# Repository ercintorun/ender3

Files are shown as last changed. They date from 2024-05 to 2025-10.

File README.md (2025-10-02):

# 🛠️ Heavily Modified Ender 3 Pro Setup

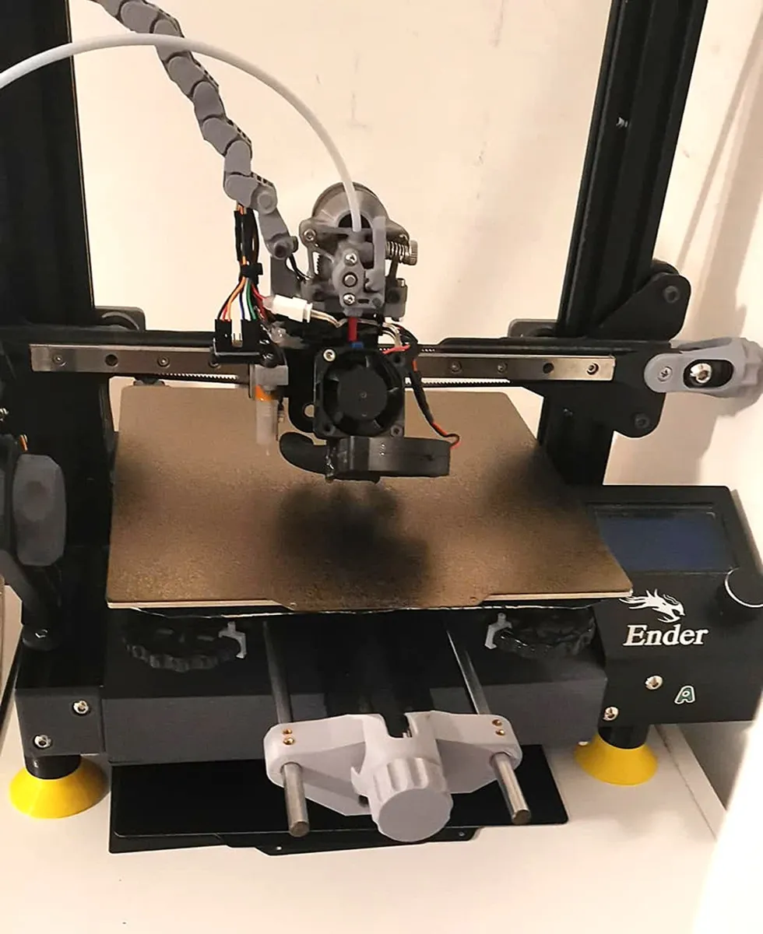
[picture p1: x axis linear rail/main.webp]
Ender 3 Pro with X-axis linear rail


---

## 🔧 Hardware Modifications

My Ender 3 Pro includes the following upgrades:

- 🧠 **Mainboard**: BTT SKR Mini E3 V2 (buy v3 to use spi for adxl345) 
- 🍓 **Controller**: Raspberry Pi  3b
- ➖ **X Axis**: Linear Rail  
- ➖ **Y Axis**: Linear Rods  
- 📐 **Sensor**: ADXL345  
- 📍 **Auto Bed Leveling**: 3DTouch  
- 🔥 **Hotend**: Bambu-style  
- 🌬️ **Part Cooling Fan**: 5015  
- 🌡️ **Hotend Cooling Fan**: 4020  

---

## 📂 Repository Contents

- 🧾 **[Klipper Installation - Configuration](klipper.md)**
- 🖨️ **[Printed Upgrade Links**](printupgrades.md)**  
- 🧪 **[Calibration-Tuning](calibration.md)**
- ⚙️ **Cura & PrusaSlicer Start/End G-code Templates**
- 🔧 **[ADXL345 on Skr Mini E3 v2.0](adxl345_on_skr_mini_e3_v2.0.md)**
- 🔧 **[Dual ADXL345 on Raspberry Pi](2_adxl345_on_raspberrypi_klipper.md)**
- 🔧 **[Chamber Temp Sensor DS18B20 on Raspberry Pi](ds18b20_chamber_temp_sensor_raspberrypi_klipper.md)**
- 🔧 **[Ender3 Stock Motor Current Configs for Klipper on SKR Mini E3 v2.0](motor_currents.md)**
- 🛒 **[Aliexpress Upgrade Links](buyupgrades.md)**

---
## 🖨️ Example Prints

- 🧵 **PETG Sample**:  
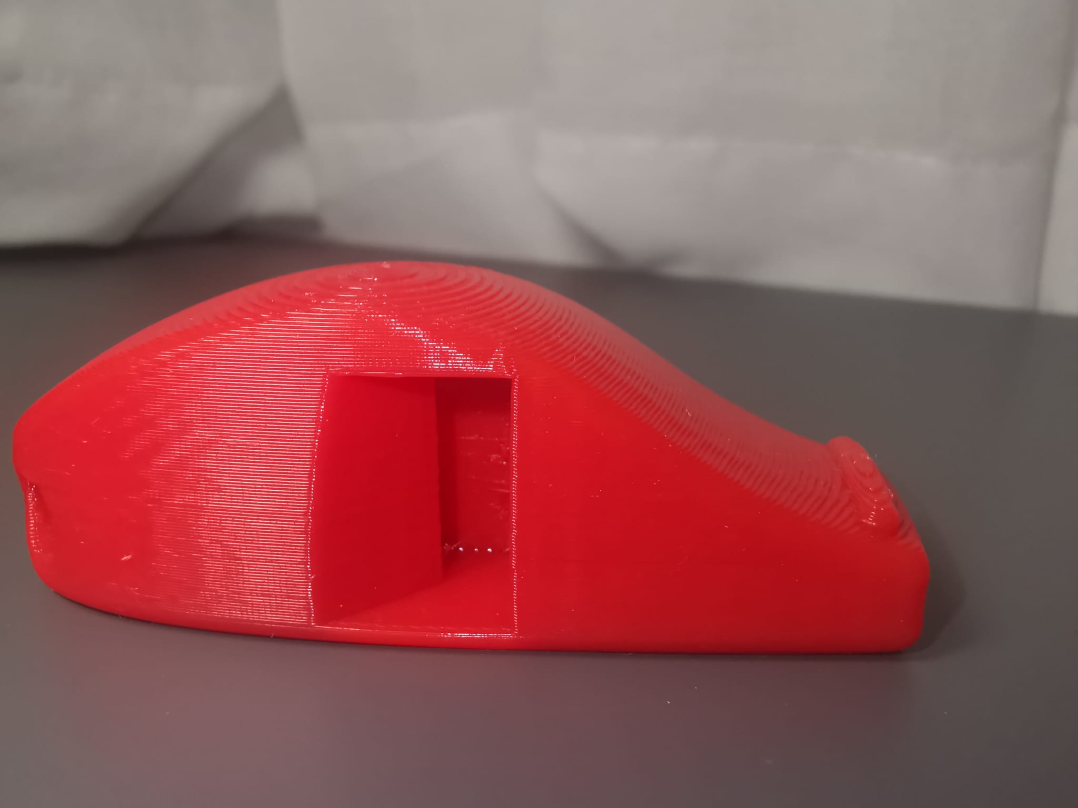
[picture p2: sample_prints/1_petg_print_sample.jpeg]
PETG sample print


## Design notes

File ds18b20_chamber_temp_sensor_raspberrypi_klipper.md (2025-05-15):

Be aware that the Klipper heating code was designed around temperature sensors that provide an update every 300ms. The ds18b20 sensor can only provide updates once every second or so. You may not be able to use a heater with db18b20. If you want to use it than you need to change some part of the heater.py code (you can find the details on https://klipper.discourse.group/t/controlling-a-chamber-heater-through-a-relay-connected-to-rpi4-via-gpio-and-monitored-with-a-ds18b20/11131/18) 

Klipper Configuration

    [mcu host]
    serial: /tmp/klipper_host_mcu
    [temperature_sensor Chamber]
    sensor_type: DS18B20
    serial_no: 10-00080291bf97
    ds18_report_time = 3.0
    sensor_mcu: host

a DS18B20 to GPIO4 (you have to enable 1wire via sudo raspi-config). Use 3.3 and a gnd port also on the raspberry pi. 

    Call sudo raspi-config
    Activate the 1-wire interface
    Reboot
    Call lsmod | grep -i w1_ to verify that the needed Kernel modules are actually loaded 

Source:
https://klipper.discourse.group/t/ds18b20-temperature-sensor-configuration/8429/4
https://klipper.discourse.group/t/controlling-a-chamber-heater-through-a-relay-connected-to-rpi4-via-gpio-and-monitored-with-a-ds18b20/11131/6

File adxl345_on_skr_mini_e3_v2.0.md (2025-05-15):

## 🔧 ADXL345on SKR Mini E3 v2.0

Use the EXP1 connector. You either connect the tft35-screen or the adxl 345 if you use the board.The alternative is to use Raspberry pi SPI pins. The difference between skr mini e3 v3.0 and 2.0  is with the accelerometer's CS pin. The V2.0 board's SPI1 port only has 6 pins, while 3.0 has 8, and it lacks the NSS pin. This board's connector does instead have an "RST" pin, but that's no use. It is not possible to use SPI ports for adxl345 on 2.0 unlike the 3.0. 

    [adxl345]
    cs_pin: PB5
    spi_software_sclk_pin: PB9
    spi_software_mosi_pin: PB8
    spi_software_miso_pin: PB15

    [resonance_tester]
    accel_chip: adxl345
    probe_points:100, 100, 20

If you would like to use the original ender cable to extend the pinouts from EXP1: 
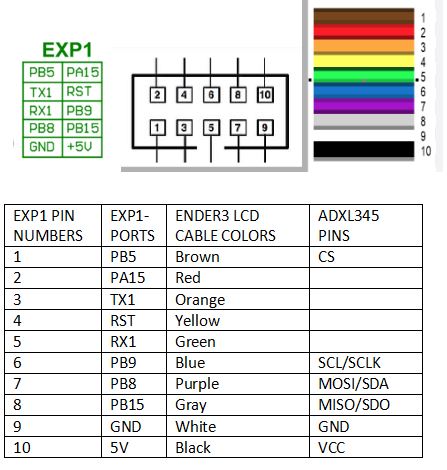
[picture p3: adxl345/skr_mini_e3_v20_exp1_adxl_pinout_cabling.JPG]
PETG sample print


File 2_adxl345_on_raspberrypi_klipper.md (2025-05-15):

## 🔧 ADXL345 Method 2 - 2 ADXL on Raspberry Pi

Follow the instructions on Klipper documentation how to install Raspberry pi as a second MCU and enabling the SPI. 
- https://www.klipper3d.org/RPi_microcontroller.html

You could use spi0 and share the mosi miso and sclk with both chips and use CE0 and CE1 as ADLX345s enable pin. SPI is not designed to use 2 devices at once on the bus but the input calibration doesn't use both at the same time so this is an acceptible setup.

Configuration

    [mcu rpi]
    serial: /tmp/klipper_host_mcu
    [adxl345 hotend]
    cs_pin: rpi:None
    spi_bus: spidev0.0
    [adxl345 bed]
    cs_pin: rpi:None
    spi_bus: spidev0.1
    [resonance_tester]
    accel_chip_x: adxl345 hotend
    accel_chip_y: adxl345 bed
    probe_points: 125, 110, 20

Both ADXL345's will share the same SDA, SDO and SCL, each will have their own CS pin. The config i posted above is accurate for what I'm about to list below for wiring. Remember the RPI MCU does the CS muxing so "cs_pin: rpi:None" is valid for both.

    Both
    SDA = RPI Pin 19 = GPIO10 (SPI0_MOSI)
    SDO = RPI Pin 21 = GPIO09 (SPI0_MISO)
    SCL = RPI Pin 23 = GPIO11 (SPI0_SCLK)
    3V3 (or VCC) = RPI Pin 01 = RPI Pin Name "3.3v DC power"
    GND = RPI Pin 06 = RPI Pin Name "Ground"

    ADXL345 hotend
    CS = RPI Pin 24 = GPIO08 (SPI0_CE0)

    ADXL345 bed
    CS = RPI Pin 26 = GPIO07 (SPI0_CE1)

Pins for spi reference as well as Klipper Doc [SPI Pinout](https://pinout.xyz/pinout/spi) 

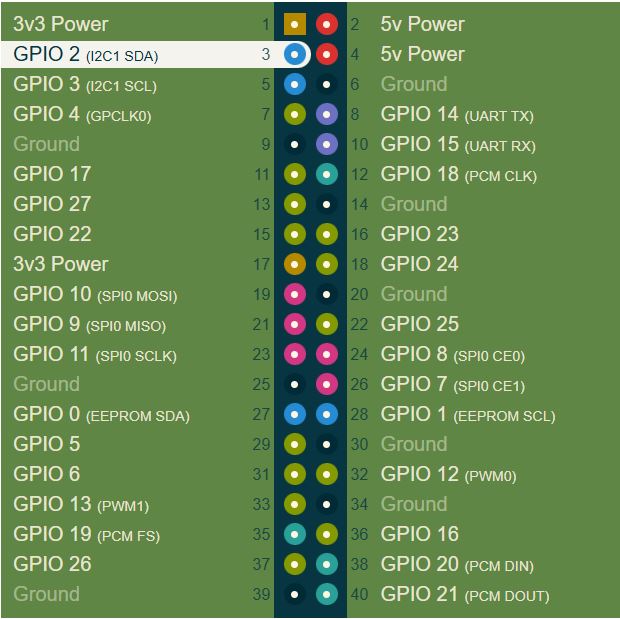
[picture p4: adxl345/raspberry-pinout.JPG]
RaspberryPi Pinout
  

Source for the information: 
- https://www.reddit.com/r/klippers/comments/qkk7un/two_adxl345s_on_one_raspberry_pi/
- https://www.reddit.com/r/klippers/comments/qkk7un/comment/hj0s9gj/

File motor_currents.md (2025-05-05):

The Ender 3's stepper motors have a max current of 840mA (594mA RMS), and running them at 580mA RMS (near max) can cause overheating and skipped steps. The 580mA value likely comes from stock settings, but for Klipper, this should be converted to RMS—about 410mA. It's recommended to set run_current to 0.410A for the X, Y, and Z motors and remove hold_current. The extruder motor can safely stay at 0.500A due to its higher 1A max rating.

source:
- https://www.reddit.com/r/klippers/comments/s3aqnv/ender3pro_skr_e3_mini_rpi3a_with_klipper_on/

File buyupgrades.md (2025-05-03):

## 🛒 Aliexpress Upgrade Links

- 🧲 [PEI Bed](https://tr.aliexpress.com/item/1005004992757753.html)  
- 🔥 [Hotend Upgrade – Bambu Style](https://tr.aliexpress.com/item/1005005193902909.html)  
- 🌀 [Nema14 Motor for Sherpa Mini](https://tr.aliexpress.com/item/1005002997600597.html)  
- ⚙️ [Sherpa Mini Gears & Bearings](https://tr.aliexpress.com/item/1005006023988927.html)  
- 🔩 [Bimetal Hotend for Stock Extruder](https://tr.aliexpress.com/item/1005002907726643.html)

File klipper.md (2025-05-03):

## 🔌 Raspberry Pi 

- **Klipper Installation**
  [`Kiauh`](https://github.com/dw-0/kiauh)
  
- **TTY Rule (Persistent Device Name)**

To make your serial devices persist across reboots, copy this file:

📄 [`49-custom.rules`](https://gist.github.com/edro15/1c6cd63894836ed982a7d88bef26e4af)  
➡️ Place into: `/etc/udev/rules.d/`

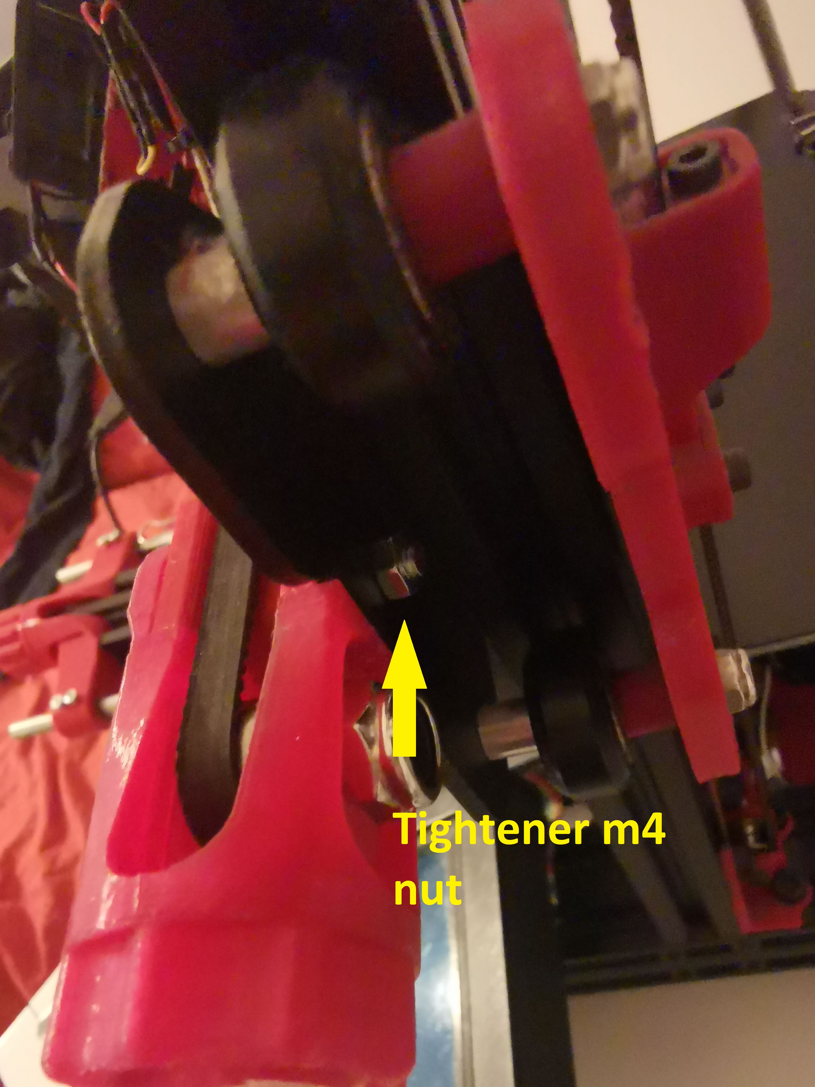
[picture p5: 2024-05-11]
x axis linear rail/tightener_nut.jpg

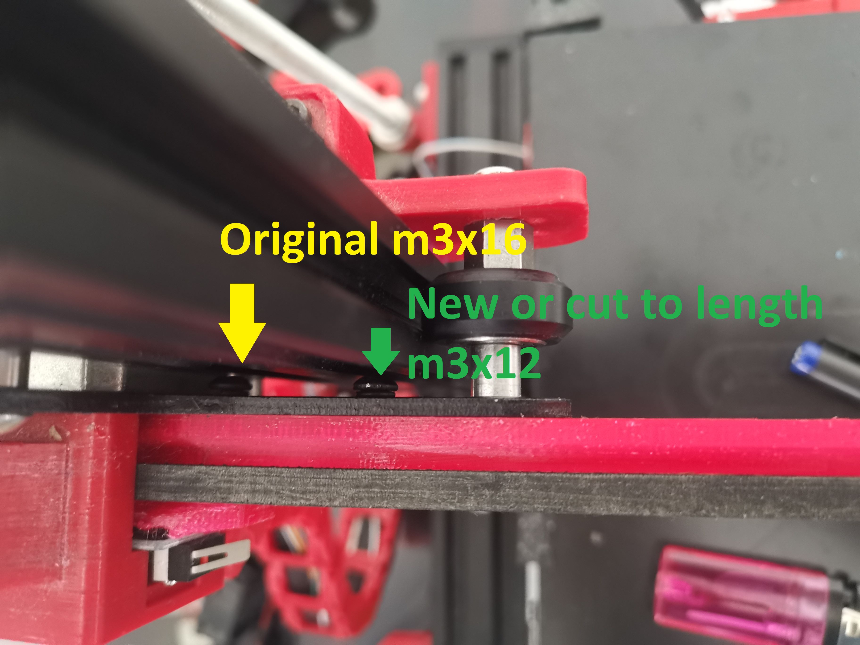
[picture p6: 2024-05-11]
x axis linear rail/rail_holder_mount_screws.jpg

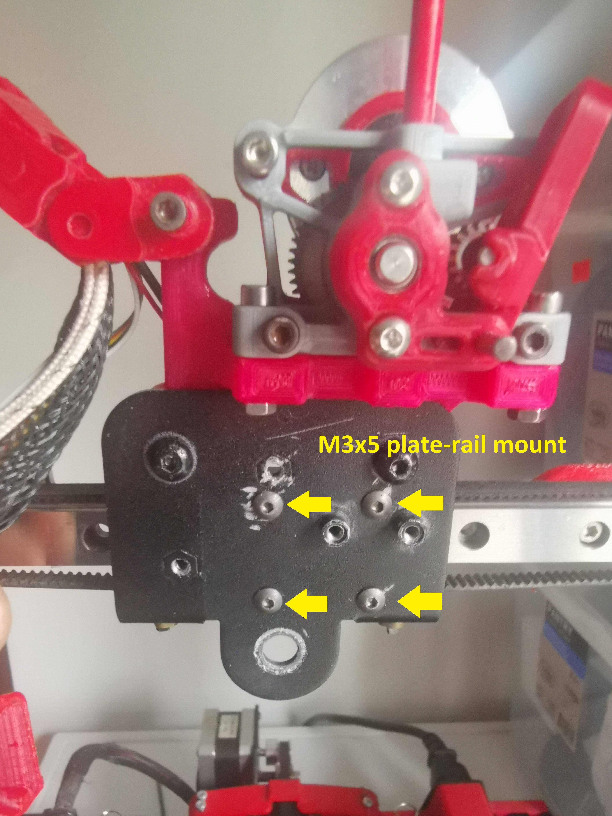
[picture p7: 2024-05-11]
x axis linear rail/rail_car_plate_mount_screws.jpg

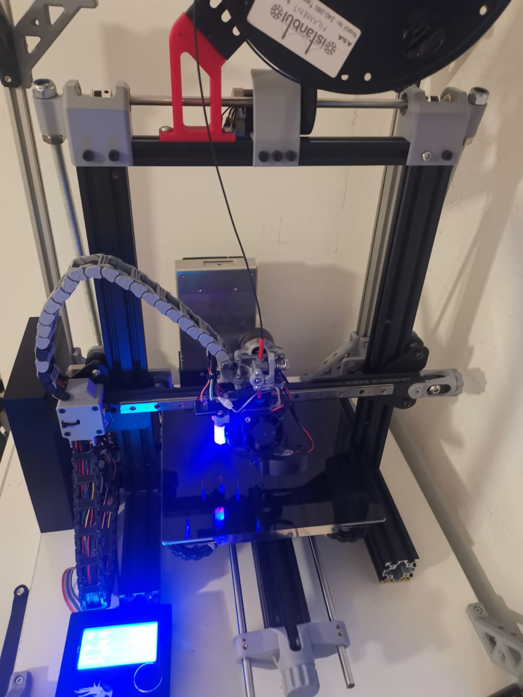
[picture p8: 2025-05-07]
x axis linear rail/main.jpeg

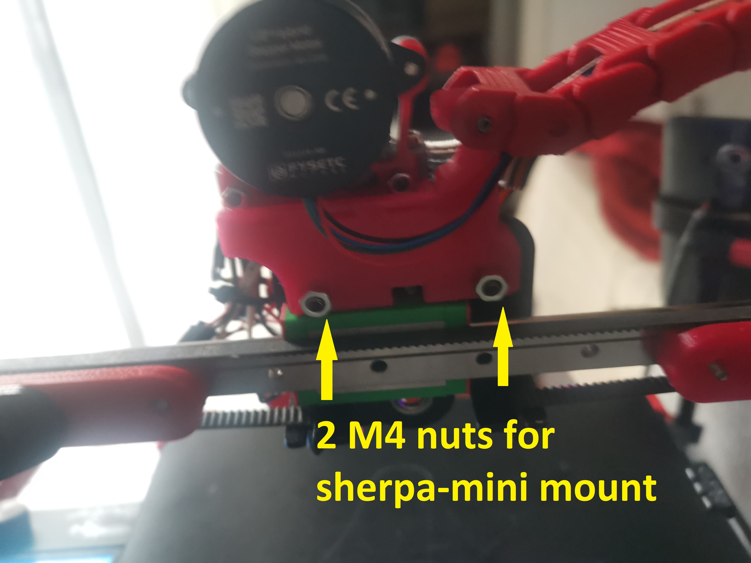
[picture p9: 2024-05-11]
x axis linear rail/sherpa_mini_mount_screws.jpg

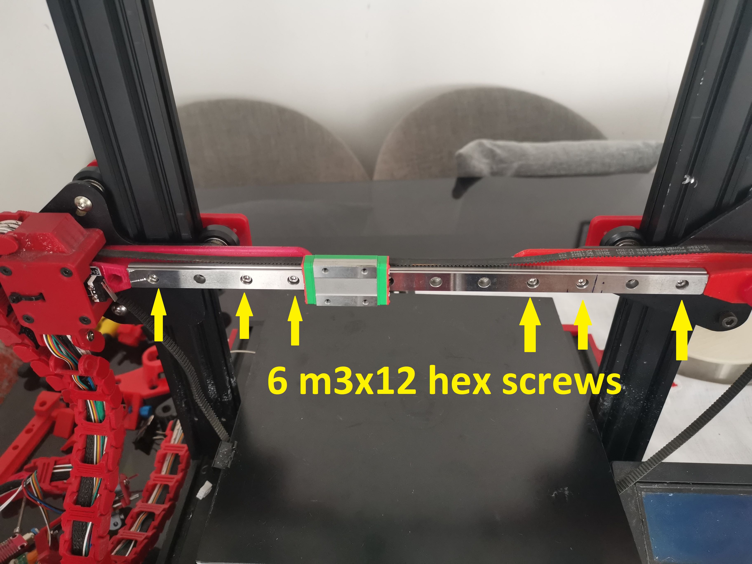
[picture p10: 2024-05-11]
x axis linear rail/linear_rail_hex_screws.jpg

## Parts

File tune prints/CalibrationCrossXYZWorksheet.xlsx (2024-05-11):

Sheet: X
3D Printer XYZ Compensation Calculator |  |  | https://www.printables.com/model/546871
axis | X
Instructions:
Only fill out the yellow fields
1) print the part from: https://www.printables.com/model/546871
2) Measure the distances as indicated in the diagram, and fill in the yellow fields
in green is the result you can use for your printer setting
in blue are the recomended toleances (gaps between parts) to be used when designing
Printer (optional) | Bambu X1C
Slicer (optional) | OrcaSlicer
Filament (optional) | Prusament Galaxy Black PLA
Standard deviation [mm] |  | 0.11 | 0.05
mean wall thickness deviation [mm] |  | -0.07 | -0.07 | constant offset (may be affected by extrusion mutiplier/flow or X-Y contour compensation)
X Scaling Multiplier Needed |  | 1.002
X Shrink Percentage |  | 99.85%
Y Scaling Multiplier Needed (from other tab) |  | 1.002
Y Shrink Percentage (from other tab) |  | 99.83%
Average XY Scale Factor Needed |  | 100.16%
Average XY Shrink Percentage |  | 99.84%
Derived design gidelines |  | Before | After Correction Applied
Tolerance needed so 50% will fit |  | 0.00 | 0.00
Tolerance needed to 84% of the prints fit |  | 0.18 | 0.05
Tolerance needed to 97% of the prints fit |  | 0.29 | 0.10
Tolerance needed to 99.8% of the prints fit |  | 0.40 | 0.15
 | length (mm) |  |  | now (mm) |  | Expected after corretion (mm)
 |  | Should Be | is | Deviation | Without offset | Deviation After Correction | Without offset
1 |  | 5 | 4.96 | -0.04 | 0.03 | -0.03 | 0.04
2 |  | 10 | 9.96 | -0.04 | 0.03 | -0.02 | 0.05
3 |  | 15 | 14.93 | -0.07 | 0.002962162162 | -0.05 | 0.03
4 |  | 20 | 19.86 | -0.14 | -0.07 | -0.11 | -0.03
5 |  | 25 | 24.82 | -0.18 | -0.11 | -0.14 | -0.07
6 |  | 50 | 49.89 | -0.11 | -0.04 | -0.03 | 0.04
7 |  | 100 | 99.78 | -0.22 | -0.15 | -0.06 | 0.02
8 |  | 150 | 149.69 | -0.31 | -0.24 | -0.06 | 0.01
9 |  | 125 | 124.78 | -0.22 | -0.15 | -0.02 | 0.06
10 |  | 75 | 74.76 | -0.24 | -0.17 | -0.12 | -0.04
11 |  | 25 | 24.82 | -0.18 | -0.11 | -0.14 | -0.07
12 |  | 20 | 19.80 | -0.20 | -0.13 | -0.17 | -0.09
13 |  | 15 | 14.93 | -0.07 | 0.002962162162 | -0.05 | 0.03
14 |  | 10 | 9.94 | -0.06 | 0.01 | -0.04 | 0.03
15 |  | 5 | 4.98 | -0.02 | 0.05 | -0.01 | 0.06
Adapted from | https://www.thingiverse.com/thing:2484766
 |  |  |  |  |  |  |  | Histogram |  | Before | After Correction
 |  |  |  |  |  |  |  | -0.5 | <=-0.5 | 0 | 0
 |  |  |  |  |  |  |  | -0.4 | -0.45 | 0 | 0
 |  |  |  |  |  |  |  | -0.3 | -0.35 | 1 | 0
 |  |  |  |  |  |  |  | -0.2 | -0.25 | 3 | 0
 |  |  |  |  |  |  |  | -0.1 | -0.15 | 5 | 5
 |  |  |  |  |  |  |  | 0 | -0.05 | 6 | 10
 |  |  |  |  |  |  |  | 0.1 | 0.05 | 0 | 0
 |  |  |  |  |  |  |  | 0.2 | 0.15 | 0 | 0
 |  |  |  |  |  |  |  | 0.3 | 0.25 | 0 | 0
 |  |  |  |  |  |  |  | 0.4 | 0.35 | 0 | 0
 |  |  |  |  |  |  |  | 0.5 | 0.45 | 0 | 0
 |  |  |  |  |  |  |  |  | >=0.5 | 0 | 0

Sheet: Y
3D Printer XYZ Compensation Calculator |  |  | https://www.printables.com/model/546871
axis | Y
Instructions:
Only fill out the yellow fields
1) print the part from: https://www.printables.com/model/546871
2) Measure the distances as indicated in the diagram, and fill in the yellow fields
in green is the result you can use for your printer setting
in blue are the recomended toleances (gaps between parts) to be used when designing
Printer (optional) | Bambu X1C
Slicer (optional) | OrcaSlicer
Filament (optional) | Prusament Galaxy Black PLA
Standard deviation [mm] |  | 0.12 | 0.05
mean wall thickness deviation [mm] |  | -0.07 | -0.07 | constant offset (may be reduced by extrusion mutiplier/flow)
Y Scaling Multiplier Needed |  | 1.002
Y Shrink Percentage |  | 99.83%
X Scaling Multiplier Needed (from other tab) |  | 1.002
X Shrink Percentage (from other tab) |  | 99.85%
Average XY Scale Factor Needed |  | 100.16%
Average XY Shrink Percentage |  | 99.84%
Derived design gidelines |  | Before | After Correction Applied
Tolerance needed so 50% will fit |  | 0.00 | 0.00
Tolerance needed to 84% of the prints fit |  | 0.19 | 0.05
Tolerance needed to 97% of the prints fit |  | 0.31 | 0.10
Tolerance needed to 99.8% of the prints fit |  | 0.43 | 0.15
 | length (mm) |  |  | now (mm) |  | Expected after corretion (mm)
 |  | Should Be | is | Deviation | Without offset | Deviation After Correction | Without offset
1 |  | 5 | 4.98 | -0.02 | 0.05 | -0.01 | 0.06
2 |  | 10 | 9.94 | -0.06 | 0.01 | -0.04 | 0.03
3 |  | 15 | 14.92 | -0.08 | -0.01 | -0.06 | 0.02
4 |  | 20 | 19.81 | -0.19 | -0.12 | -0.16 | -0.08
5 |  | 25 | 24.83 | -0.17 | -0.10 | -0.13 | -0.06
6 |  | 50 | 49.82 | -0.18 | -0.11 | -0.10 | -0.02
7 |  | 100 | 99.74 | -0.26 | -0.19 | -0.10 | -0.02
8 |  | 150 | 149.63 | -0.37 | -0.30 | -0.12 | -0.05
9 |  | 125 | 124.81 | -0.19 | -0.12 | 0.02 | 0.09
10 |  | 75 | 74.78 | -0.22 | -0.15 | -0.10 | -0.02
11 |  | 25 | 24.82 | -0.18 | -0.11 | -0.14 | -0.07
12 |  | 20 | 19.84 | -0.16 | -0.09 | -0.13 | -0.05
13 |  | 15 | 14.93 | -0.07 | 0.003454054054 | -0.05 | 0.03
14 |  | 10 | 9.94 | -0.06 | 0.01 | -0.04 | 0.03
15 |  | 5 | 4.98 | -0.02 | 0.05 | -0.01 | 0.06
Adapted from | https://www.thingiverse.com/thing:2484766
 |  |  |  |  |  |  |  | Histogram |  | Before | After Correction
 |  |  |  |  |  |  |  | -0.5 | <=-0.5 | 0 | 0
 |  |  |  |  |  |  |  | -0.4 | -0.45 | 0 | 0
 |  |  |  |  |  |  |  | -0.3 | -0.35 | 1 | 0
 |  |  |  |  |  |  |  | -0.2 | -0.25 | 2 | 0
 |  |  |  |  |  |  |  | -0.1 | -0.15 | 6 | 5
 |  |  |  |  |  |  |  | 0 | -0.05 | 6 | 9
 |  |  |  |  |  |  |  | 0.1 | 0.05 | 0 | 1
 |  |  |  |  |  |  |  | 0.2 | 0.15 | 0 | 0
 |  |  |  |  |  |  |  | 0.3 | 0.25 | 0 | 0
 |  |  |  |  |  |  |  | 0.4 | 0.35 | 0 | 0
 |  |  |  |  |  |  |  | 0.5 | 0.45 | 0 | 0
 |  |  |  |  |  |  |  |  | >=0.5 | 0 | 0

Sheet: Z
3D Printer XYZ Compensation Calculator |  |  | https://www.printables.com/model/546871
axis | Z
Instructions:
Only fill out the yellow fields
1) print the part from: https://www.printables.com/model/546871
2) Measure the distances as indicated in the diagram, and fill in the yellow fields
in green is the result you can use for your printer setting
in blue are the recomended toleances (gaps between parts) to be used when designing
Printer (optional) | Bambu X1C
Slicer (optional) | OrcaSlicer
Filament (optional) | Prusament Galaxy Black PLA
Standard deviation [mm] |  | 0.08 | 0.07
mean wall thickness deviation [mm] |  | -0.29 | -0.29 | constant offset (may be reduced by extrusion mutiplier/flow)
Z Scale Factor Needed |  | 100.05%
Z Shrink Percentage |  | 99.95%
Derived design gidelines |  | Before | After Correction Applied
Tolerance needed so 50% will fit |  | 0.00 | 0.00
Tolerance needed to 84% of the prints fit |  | 0.37 | 0.07
Tolerance needed to 97% of the prints fit |  | 0.44 | 0.13
Tolerance needed to 99.8% of the prints fit |  | 0.52 | 0.20
 | length (mm) |  |  | now (mm) |  | Expected after corretion (mm)
 |  | Should Be | is | Deviation | Without offset | Deviation After Correction | Without offset
1 |  | 5 | 4.70 | -0.30 | -0.01 | -0.30 | -0.01
2 |  | 5 | 4.64 | -0.36 | -0.07 | -0.36 | -0.07
3 |  | 5 | 4.67 | -0.33 | -0.04 | -0.33 | -0.04
4 |  | 5 | 4.70 | -0.30 | -0.01 | -0.30 | -0.01
5 |  | 50 | 49.77 | -0.23 | 0.06 | -0.20 | 0.08
6 |  | 75 | 74.80 | -0.20 | 0.09 | -0.16 | 0.13
7 |  | 100 | 99.71 | -0.29 | -0.003058078142 | -0.24 | 0.05
8 |  | 125 | 124.61 | -0.39 | -0.10 | -0.33 | -0.04
9 |  | 150 | 149.55 | -0.45 | -0.16 | -0.37 | -0.09
Adapted from | https://www.thingiverse.com/thing:2484766
 |  |  |  |  |  |  |  | Histogram |  | Before | After Correction
 |  |  |  |  |  |  |  | -0.5 | <=-0.5 | 0 | 0
 |  |  |  |  |  |  |  | -0.4 | -0.45 | 1 | 0
 |  |  |  |  |  |  |  | -0.3 | -0.35 | 5 | 4
 |  |  |  |  |  |  |  | -0.2 | -0.25 | 3 | 4
 |  |  |  |  |  |  |  | -0.1 | -0.15 | 0 | 1
 |  |  |  |  |  |  |  | 0 | -0.05 | 0 | 0
 |  |  |  |  |  |  |  | 0.1 | 0.05 | 0 | 0
 |  |  |  |  |  |  |  | 0.2 | 0.15 | 0 | 0
 |  |  |  |  |  |  |  | 0.3 | 0.25 | 0 | 0
 |  |  |  |  |  |  |  | 0.4 | 0.35 | 0 | 0
 |  |  |  |  |  |  |  | 0.5 | 0.45 | 0 | 0
 |  |  |  |  |  |  |  |  | >=0.5 | 0 | 0

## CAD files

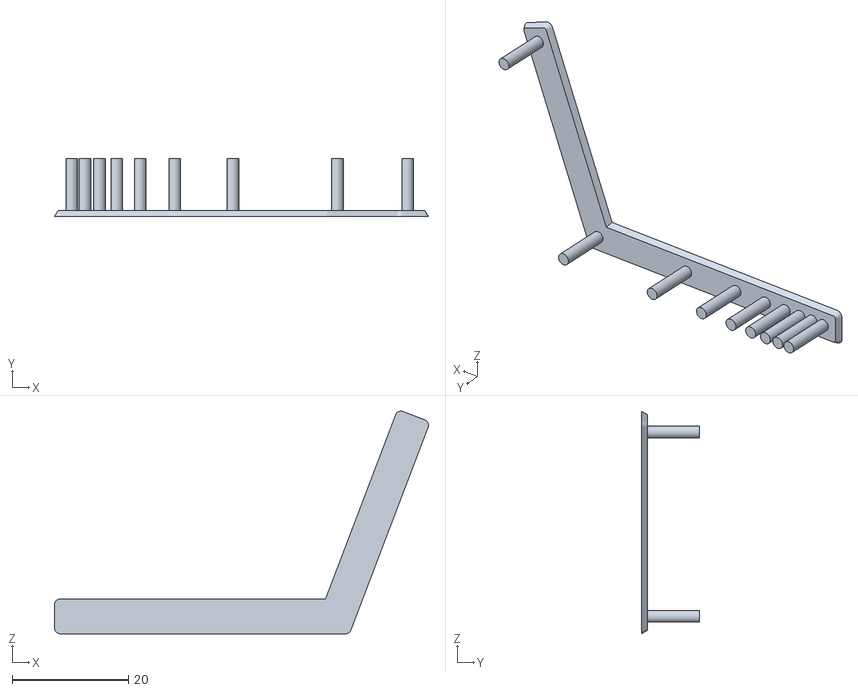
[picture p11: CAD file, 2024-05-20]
tune prints/Full Retraction Test.stl
64.4 x 10.0 x 38.4

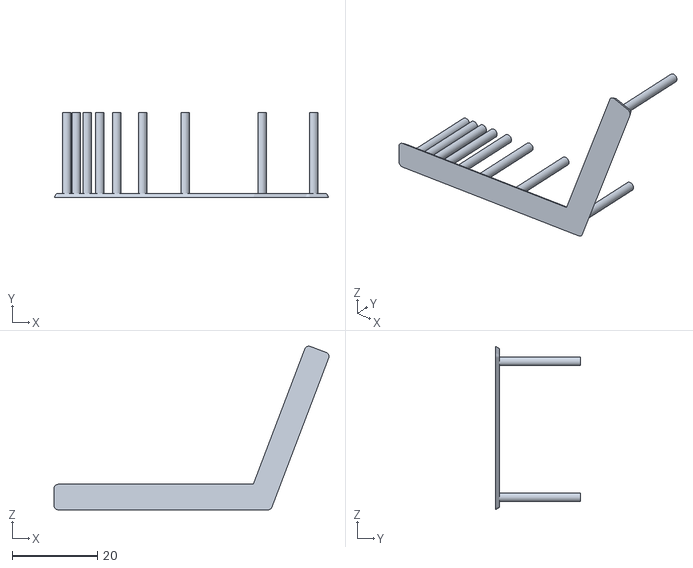
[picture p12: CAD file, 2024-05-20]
tune prints/Full Retraction Test Double Lenght.stl
64.4 x 20.0 x 38.4

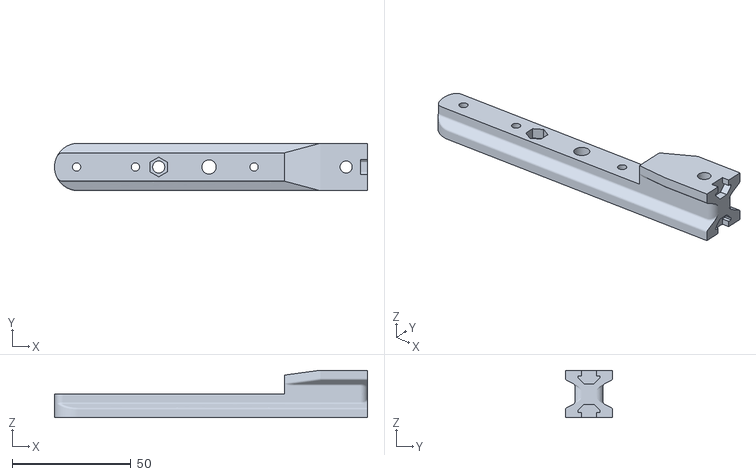
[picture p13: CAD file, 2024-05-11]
x axis linear rail/Right_Rail_Holder_Original.stl
131.9 x 20.0 x 20.0

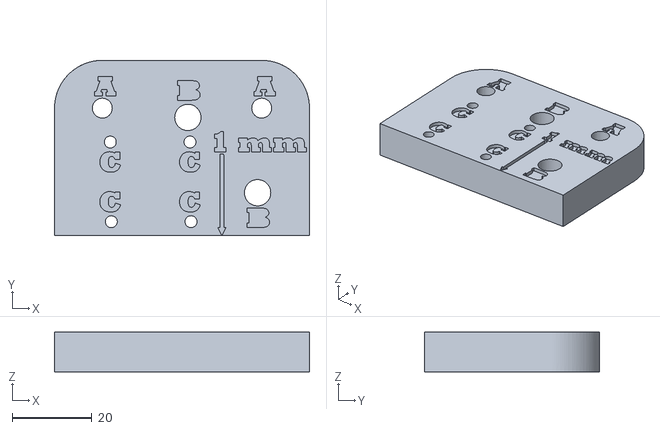
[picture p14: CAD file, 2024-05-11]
x axis linear rail/Drill_Guide_V2.stl
64.0 x 44.0 x 10.0

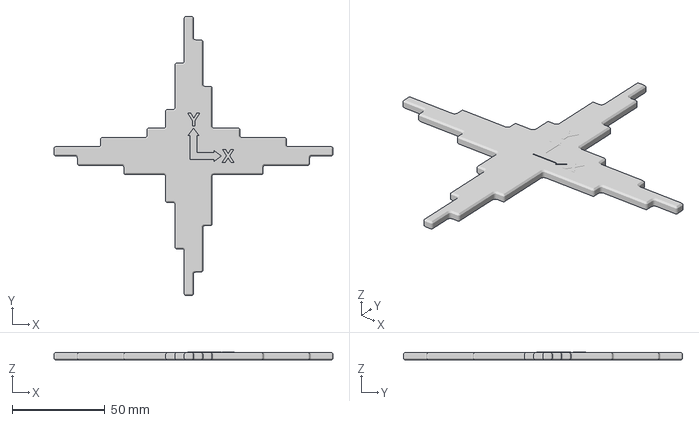
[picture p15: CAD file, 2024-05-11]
tune prints/CaliCross_XY.3mf
150.0 x 150.0 x 4.25 mm

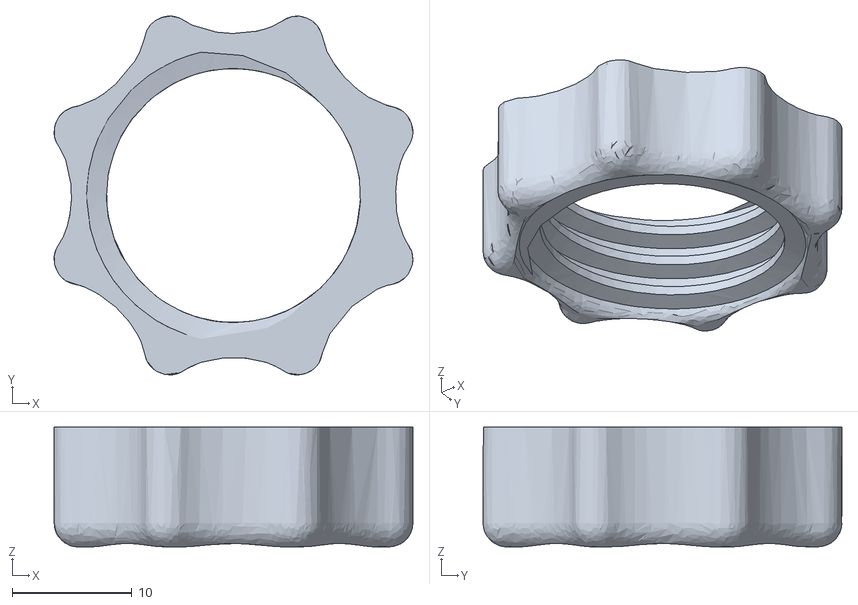
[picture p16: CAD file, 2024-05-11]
x axis linear rail/Tensioner_part2_original_split.stl
29.9 x 29.9 x 10.0

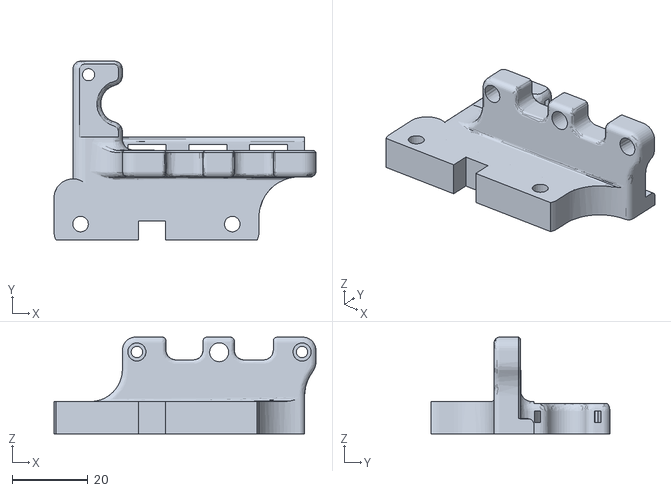
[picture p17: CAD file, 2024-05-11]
x axis linear rail/Sherpa_Mini_Mount_Remixed.stl
69.0 x 47.1 x 25.5

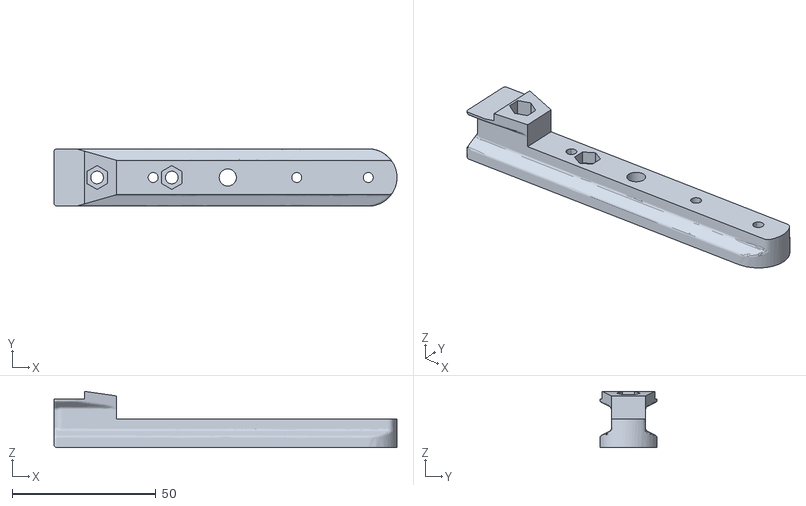
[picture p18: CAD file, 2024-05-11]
x axis linear rail/Left_Rail_Holder_Remixed.stl
119.4 x 20.0 x 19.6

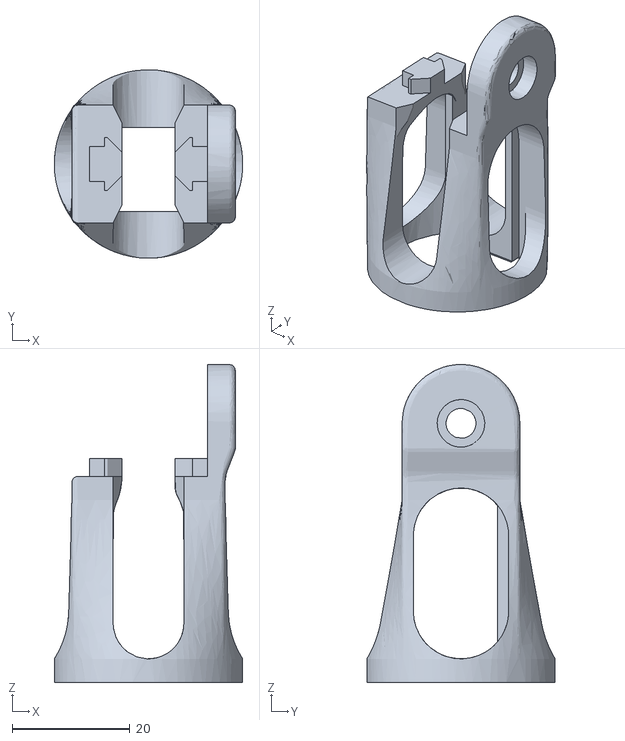
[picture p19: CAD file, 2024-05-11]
x axis linear rail/tensioner_part3_original_split.stl
32.0 x 32.0 x 54.0

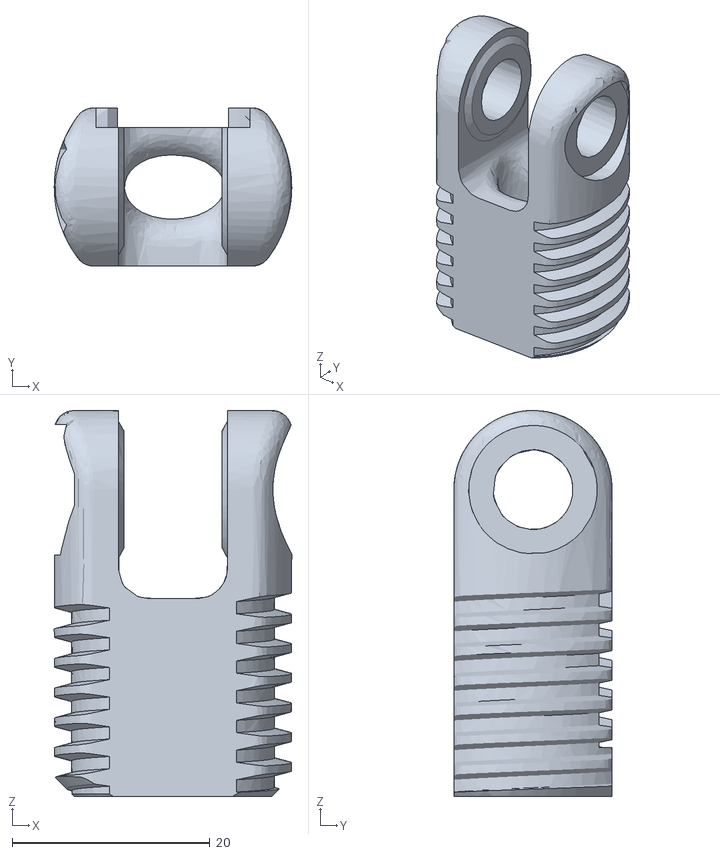
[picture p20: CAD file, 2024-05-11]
x axis linear rail/Tensioner_part1_original_split.stl
24.0 x 16.0 x 39.0

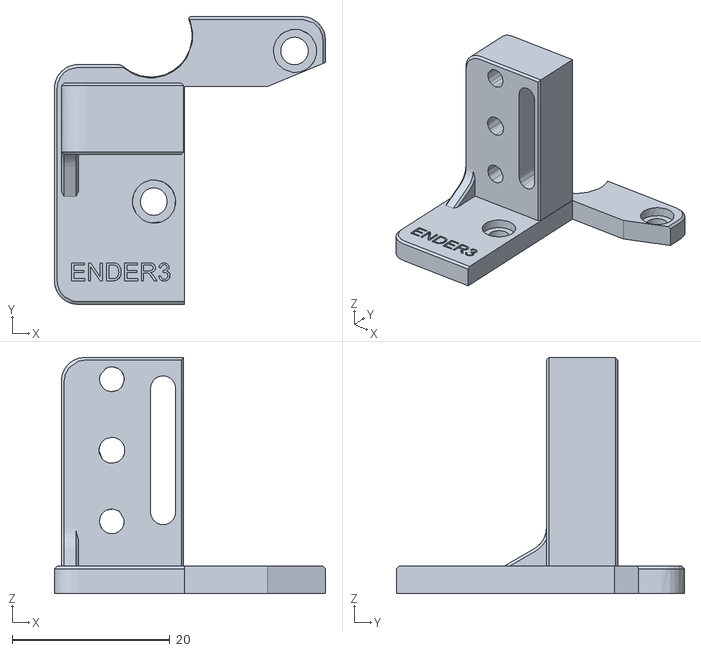
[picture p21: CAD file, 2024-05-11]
x axis linear rail/bl_touch_mount_Remixed.stl
34.4 x 36.5 x 30.0

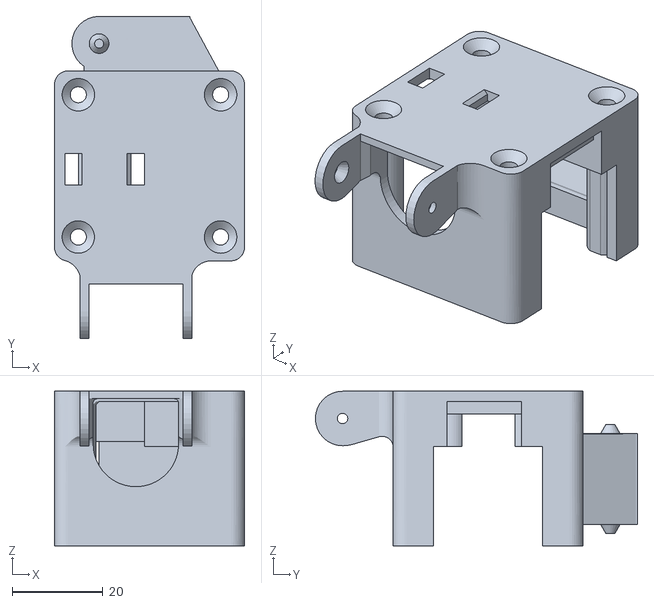
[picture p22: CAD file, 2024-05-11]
x axis linear rail/Chain_Top_Mount_X.stl
41.8 x 70.9 x 34.0

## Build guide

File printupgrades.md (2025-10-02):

## 🧱 Printed Upgrade Links

### ➖ Y-Axis Linear Rods

- [Linear Rod/Shaft Upgrade](https://www.printables.com/model/446502-ender-3-v2-x-and-y-linear-rodshaft-upgrade)  
- [Y Rod Holder + Tensioner](https://www.printables.com/model/795701-ender-3-pro-front-y-rod-holder-belt-tensioner)

### ➖ X-Axis Linear Rail

- [X Linear Rail + Sherpa Mini Mount](https://www.printables.com/model/862213-ender-3-pro-x-linear-rail-and-sherpa-mini-mount)
 
### ⚙️ Belted Z-Axis

- [Belted Z Conversion](https://github.com/kevinakasam/BeltDrivenEnder3)

### 🏗️ Z-Brace for Belted Z

- [Strong Top + Z-Brace](https://www.printables.com/model/454951-strong-top-for-belt-driven-ender-3-with-z-brace)  
- [Thingiverse Z-Brace #2](https://www.thingiverse.com/thing:3719799/files) *(Use `bottom_left` and `bottom_right`)*

### 💨 Fan Duct Options

- [Mini Me Remix (Height Adjustable)](https://www.printables.com/model/233046-minime-remix-height-adjustable-4010-5015-part-cool) *(Bambu hotend)*  
- [Mini Me V4 Duct](https://www.printables.com/model/197957-mini-me-v4-lightweight-ender3-hotend-duct-stock-pa) *(Stock hotend)*  
- [Volcano Nozzle Duct](https://www.thingiverse.com/thing:5141104)

### 📍 BLTouch Mounts

- [BLTouch Mount](https://www.thingiverse.com/thing:3003725)  
- [BLTouch Spacers (2mm / 5mm / 10mm)](https://www.printables.com/model/106004-bltouch-spacer-2mm5mm-and-10mmoff-brand/files)
- [ADXL345 Mount for BLTouch](https://www.printables.com/model/311258-adxl345-bltouch-mount-for-ender-3-v2)

### 🧵 Sherpa Mini Extruder

Print the parts out of **ASA**, **ABS**, or **PETG**.

- [Sherpa Mini STLs](https://github.com/Annex-Engineering/Sherpa_Mini-Extruder/tree/master/STLs)

###  Electronics Enclosure
- [Front Electronics Enclosure].(https://www.printables.com/model/1423813-ender-3-pro-front-electronics-enclosure)

### 🔩 X-Belt Tensioners

*Note: Only for standard Ender 3 Pro (not compatible with linear rail X-axis).*

- [Tensioner A](https://www.thingiverse.com/thing:3319649)  
- [Tensioner B](https://www.thingiverse.com/thing:3455739)

**Correct Files to Use**:
- `Ender_3_Pro_Tevo_Tornado_2mm_lower_body`  
- `ender_3_pro_tevo_tornado_x_tensioner_knob_misterguru`  
- `tensioner_slider_solid_screwheadclearance`

### 🛏️ Bed Lock

- [Bed Lock Model](https://www.printables.com/model/412791-ender-3-pro-v2-s1-ender-5-bed-lock)

### 🔇 Anti-Vibration Feet

- [Vibration-Dampening Feet](https://www.printables.com/model/385532-ender-3-pro-voron-themed-electronics-enclosure/files)

**Files to Use**:
- `foot-tpu`  
- `foot-extension`

### Y Motor Mount
- [Y Motor Mount](https://www.printables.com/model/632200-ender-3-prov2-y-axis-motor-mount)

### Filament Spool Holder
- [Filament Spool Holder by AngryHulk](https://www.thingiverse.com/thing:4834202)

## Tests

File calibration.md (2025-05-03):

## 🔧 Calibration Tools

### 🧪 Linear Advance Calibration

- [Ellis3DP Pressure Advance Tool](https://ellis3dp.com/Pressure_Linear_Advance_Tool/)

### 📏 Dimensional Accuracy

- [CaliCross](https://www.printables.com/model/546871-calicross-a-handy-tool-for-3d-printer-dimensional-)

### 🔁 Retraction Test

- [Full Retraction Test Model](https://www.printables.com/model/398911-full-retraction-test)  
  *Tip: Run tests with varied distances. Enable "Minimum travel distance for retraction".*

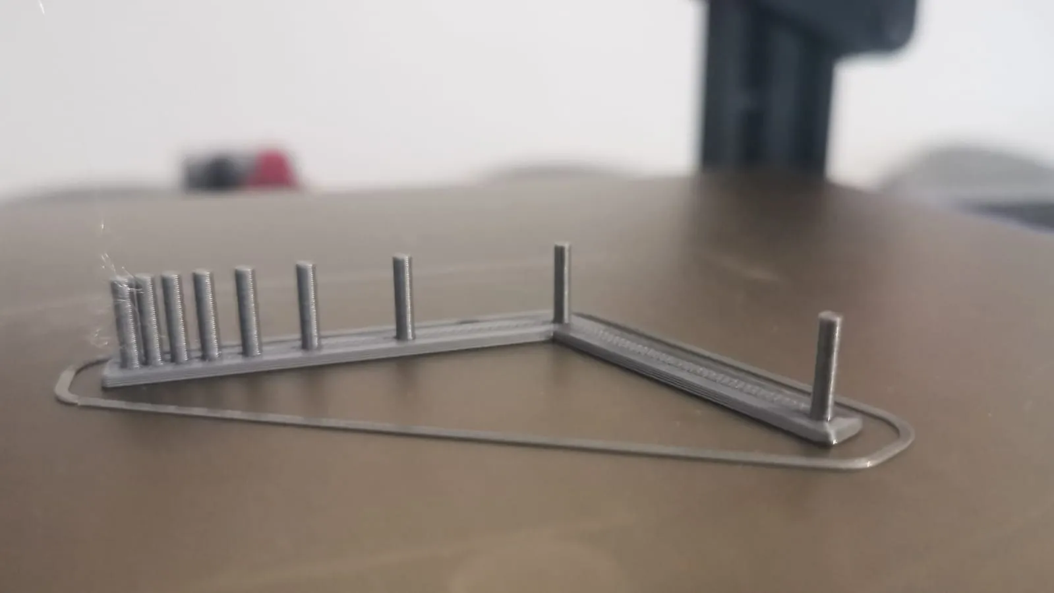
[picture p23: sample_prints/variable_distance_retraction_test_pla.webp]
Retraction Test Print
  

### 📦 Flow Calibration

- [Flow Cube Model](https://www.printables.com/model/81314-flow-calibration-cube/files)  
- [Slic3r Flow Math Docs](https://manual.slic3r.org/advanced/flow-math)

💡 **Pro Tip**:  
Print multiple mini parts to assess surface quality. For cubes, use fixed wall thickness over slicer auto-calculated settings.

🔍 **Slicer Differences**:
- **Cura**: Rectangular cross-sections  
- **PrusaSlicer / Slic3r**: Hemispherical logic for single-wall thickness

[🧠 Community Flow Math Deep Dive](https://community.ultimaker.com/topic/28492-flow-calculations/?do=findComment&comment=280032)

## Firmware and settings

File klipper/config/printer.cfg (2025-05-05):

# [include mainsail.cfg]
[virtual_sdcard]
path: /home/pi/printer_data/gcodes

#For adxl on EXP port enable adxl_exp.cfg and disable lcd_menus.cfg. Below is for using tft-35
#[include adxl_exp.cfg]
[include tft35_menus.cfg]

#For adxl on Raspberry Pi enable adxl_raspi.cfg
[include adxl_raspi.cfg]

#Printer Macros
[include printer_macros.cfg]

#Filament Runout Sensor
[include filament_runout_sensor.cfg]

#3dtouch enable
[include 3dtouch.cfg]

[gcode_macro T0]
gcode:

[stepper_x]
step_pin: PB13
dir_pin: !PB12
enable_pin: !PB14
microsteps: 16
rotation_distance:40.129
endstop_pin:tmc2209_stepper_x:virtual_endstop
position_endstop: 2
position_max: 248
homing_speed: 20
homing_retract_dist: 0

[tmc2209 stepper_x]
uart_pin: PC11
tx_pin: PC10
uart_address: 0
run_current: 0.410
#stealthchop_threshold: 999999
#interpolate:False
diag_pin: ^PC0      # Set to MCU pin connected to TMC DIAG pin
driver_SGTHRS: 58  # 255 is most sensitive value, 0 is least sensitive

[stepper_y]
step_pin: PB10
dir_pin: !PB2
enable_pin: !PB11
microsteps: 16
rotation_distance:40.015
endstop_pin: tmc2209_stepper_y:virtual_endstop
position_endstop: -1
position_max: 235
position_min: -1
homing_speed: 20
homing_retract_dist: 0

[tmc2209 stepper_y]
uart_pin: PC11
tx_pin: PC10
uart_address: 2
run_current: 0.410
#stealthchop_threshold: 999999
#interpolate:False
diag_pin: ^PC1      # Set to MCU pin connected to TMC DIAG pin
driver_SGTHRS: 60  # 255 is most sensitive value, 0 is least sensitive


[stepper_z]
step_pin: PB0
dir_pin: !PC5
enable_pin: !PB1
microsteps: 16
rotation_distance: 7.987
endstop_pin: probe:z_virtual_endstop
position_max: 250
position_min: -6

[tmc2209 stepper_z]
uart_pin: PC11
tx_pin: PC10
uart_address: 1
run_current: 0.5

[extruder]
step_pin: PB3
dir_pin: PB4
enable_pin: !PD2
microsteps: 16
rotation_distance:21.988
gear_ratio:50:10
nozzle_diameter: 0.400
filament_diameter: 1.750
heater_pin: PC8
sensor_type: ATC Semitec 104NT-4-R025H42G
#sensor_type: EPCOS 100K B57560G104F
#sensor_type: Generic 3950
sensor_pin: PA0
min_temp: 0
max_temp: 300
max_extrude_only_distance:100.0
pressure_advance:0.035
max_power: 0.85


[tmc2209 extruder]
uart_pin: PC11
tx_pin: PC10
uart_address: 3
run_current: 0.6

[heater_bed]
heater_pin: PC9
sensor_type: ATC Semitec 104GT-2
sensor_pin: PC3
control: pid
pid_Kp=73.704
pid_Ki=1.376
pid_Kd=986.711
min_temp: 0
max_temp: 110

[heater_fan heatbreak_cooling_fan]
pin: PC7
fan_speed: 0.8


[fan]
pin: PC6


[mcu]
serial: /dev/ttyPrinter

[printer]
kinematics: cartesian
max_velocity: 300
max_accel: 3500
max_z_velocity: 5
max_z_accel: 100

[static_digital_output usb_pullup_enable]
pins: !PA14


[bed_screws]
screw1: 50,50
screw2: 50,190
screw3: 200,190
screw4: 200,50

[input_shaper]
shaper_freq_x:72.8
shaper_freq_y:39.8
shaper_type_x: ei
shaper_type_y: mzv

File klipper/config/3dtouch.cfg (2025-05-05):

[bltouch]
sensor_pin: ^PC14
control_pin: PA1

x_offset: -42
y_offset: -11
z_offset: 1.12
stow_on_each_sample: true
#z_offset Higher numbers = closer to bed
samples: 1
speed: 1

probe_with_touch_mode: False
#pin_up_reports_not_triggered: False
pin_up_touch_mode_reports_triggered: False

[safe_z_home]
home_xy_position: 125,125
speed: 50
z_hop: 10
z_hop_speed: 5

[bed_mesh]
speed: 80
horizontal_move_z: 5
mesh_min: 10,10
mesh_max: 205,220
#208,221
#probe_count: 6,6
#mesh_pps: 2,2
#fade_start: 1 
#fade_end: 10
#fade_target: 0
fade_start: 0.6
fade_end: 10.0
probe_count: 7,7 # Values should be odd, so one point is directly at bed center
algorithm: bicubic

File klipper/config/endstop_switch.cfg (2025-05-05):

#If you are not going to use "sensorless homing" then you need to use the standard endstop switch, below configuration is a sample: 

[stepper_x]
step_pin: PB13
dir_pin: !PB12
enable_pin: !PB14
microsteps: 16
rotation_distance:40.129
endstop_pin: ^PC0
position_endstop: 2
position_max: 248
homing_speed: 50

[tmc2209 stepper_x]
uart_pin: PC11
tx_pin: PC10
uart_address: 0
run_current: 0.560
#stealthchop_threshold: 999999
#interpolate:False

[stepper_y]
step_pin: PB10
dir_pin: !PB2
enable_pin: !PB11
microsteps: 16
rotation_distance:40.015
endstop_pin: ^PC1
position_endstop: -1
position_max: 235
position_min: -1
homing_speed: 50

[tmc2209 stepper_y]
uart_pin: PC11
tx_pin: PC10
uart_address: 2
run_current: 0.56
#stealthchop_threshold: 999999
#interpolate:False
